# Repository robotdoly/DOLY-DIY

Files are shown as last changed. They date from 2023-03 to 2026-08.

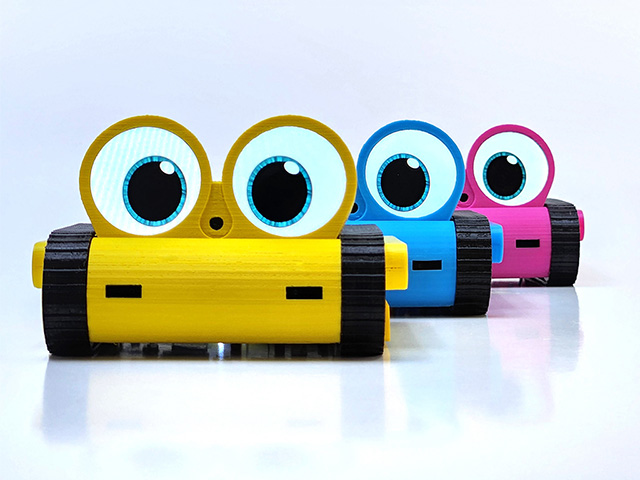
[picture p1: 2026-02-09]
Guide/web/assets/images/printable_doly.jpg

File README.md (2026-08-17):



# DOLY-DIY

Doly robot project repository including **hardware/design files + electronics + software (SDK, libraries, and examples)**.

This repo is meant to be an **all-in-one** place to **learn, remix, and build** the DOLY robot.

---

## What’s included

- **Hardware / Mechanical**
  - CAD / 3D models (STL/STEP/etc.)
  - Assembly references

- **Electronics**
  - Interactive BOMs
  - Schematics / PCB files

- **Software**
  - SDK (C++ & Python)
  - Shared libraries used by the robot
  - Example code (C++ & Python)

- **Documentation**
  - [3D printable Doly assembly guide](https://robotdoly.github.io/DOLY-DIY/maker/)
  - [C++ API documentation](https://robotdoly.github.io/DOLY-DIY/cpp/)
  - [Python API documentation](https://robotdoly.github.io/DOLY-DIY/python/)
  - [AI Integration Developer FAQ](https://github.com/robotdoly/DOLY-DIY/blob/main/SDK/docs/AI_Integration_Developer_FAQ.md)

---

## Repository structure

- `Printables/` — CAD, STLs, STEP
- `Electronics/` — schematics, PCB files, interactive BOMs  
- `SDK/` — SDK, libraries, documents and examples 
- `Guide/`  — 3D printable maker guide,  
- `Images/` — project image files
- `Add-ons/` — add-on files 

---

## Contributing

Contributions are welcome!

Good contributions include:
- bug fixes
- documentation improvements
- new examples
- SDK improvements
- 3D printable add-ons

Please contact us via the [community page](https://community.doly.ai/public/t/contribute); let's integrate your contribution and ensure you receive proper credit.

---

## License

This project is licensed under **CC BY-NC-SA 4.0** (Attribution–NonCommercial–ShareAlike).

See the `LICENSE` file for full terms.  

---

## Links

- Shop: https://shop.doly.ai
- Website: https://doly.ai
- Community: https://community.doly.ai
- Instagram: https://www.instagram.com/robotdoly/
- Facebook: https://www.facebook.com/robotdoly/
- Youtube: https://www.youtube.com/@robotdoly
- GitHub repo: https://github.com/robotdoly/DOLY-DIY

---

## Credits

- Created by **Levent Erenler**
- Commercial use is not permitted. Commercial licenses are available from Limitbit Inc.

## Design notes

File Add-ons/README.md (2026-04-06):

### Visit [doly.ai/add-ons/](https://doly.ai/add-ons/) to view all available add-ons.

For support, questions, or sharing your own designs, please visit the Doly [community](https://community.doly.ai/public/t/add-ons) forum.

Base template design files for custom add-ons can be found in [Add-ons/helpers/base_template](https://github.com/robotdoly/DOLY-DIY/tree/main/Add-ons/helpers/base_template).

Doly servo model files can be found in [Add-ons/helpers/servo](https://github.com/robotdoly/DOLY-DIY/tree/main/Add-ons/helpers/servo).

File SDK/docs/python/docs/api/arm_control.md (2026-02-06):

# ArmControl API reference

Import:

```python
import doly_arm
```

This page documents the public API exposed by the `doly_arm` Python module.

## Enums

### `ArmErrorType`

Values:

- `Abort`
- `Motor`

### `ArmSide`

Values:

- `Both`
- `Left`
- `Right`

### `ArmState`

Values:

- `Running`
- `Completed`
- `Error`

## Classes

### `ArmData`

**Fields**

- **side**
- **angle**

### `ArmEventListener`

Listener interface. Implement this class and register it with `add_listener()` to receive events.

**Methods**

- `onArmComplete(id: int, side: ArmSide) -> None`
  - Called when an arm command completes successfully.
- `onArmError(id: int, side: ArmSide, error_type: ArmErrorType) -> None`
  - Called when an arm command ends with an error.
- `onArmStateChange(side: ArmSide, state: ArmState) -> None`
  - Called when the arm state changes.
- `onArmMovement(side: ArmSide, degree_change: float) -> None`
  - Called to report incremental motion events.

## Functions

### `add_listener(listener: ArmEventListener, priority: bool = False) -> None`

Register a listener object to receive arm events.

**Parameters**

- **listener**: Pointer to a listener instance (must not be null).
- **priority**: If `True`, the listener is inserted with priority ordering (implementation-defined). (default: `False`)

**Notes**

- Callbacks are typically invoked from an internal worker/event thread.

### `remove_listener(listener: ArmEventListener) -> None`

Unregister a listener object.

**Parameters**

- **listener**: Pointer previously passed to AddListener().

### `on_complete(cb: py::function) -> None`

Set a static complete callback (replaces any previous one).
Tip: If you want multiple handlers, use a Python dispatcher function.

**Parameters**

- **cb**:

### `on_error(cb: py::function) -> None`

Set a static error callback (replaces any previous one). Tip: If you want multiple handlers, use a Python dispatcher function.

**Parameters**

- **cb**:

### `on_state_change(cb: py::function) -> None`

Set a static state change callback (replaces any previous one). Tip: If you want multiple handlers, use a Python dispatcher function.

**Parameters**

- **cb**:

### `on_movement(cb: py::function) -> None`

Set a static movement callback (replaces any previous one). Tip: If you want multiple handlers, use a Python dispatcher function.

**Parameters**

- **cb**:

### `clear_listeners() -> None`

Unregister all static callbacks and clear stored Python functions.

### `init() -> int`

Initialize the arm subsystem.

This must be called once before other control functions.

**Returns**

- `int`:

```text
Status code: - 0 : success - 1 : already initialized - -1 : left servo enable pin set failed - -2 : right servo enable pin set failed
```

**Notes**

- After successful init(), isActive() should return true.

### `dispose() -> int`

Dispose/stop the arm subsystem and release resources. Removes the call back functions.

**Returns**

- `int`:

```text
Status code: - 0 : success - 1 : not initialized
```

### `is_active() -> bool`

Check whether the subsystem is active (initialized and running).

**Returns**

- `bool`:

```text
true if active, false otherwise.
```

### `abort(side: ArmSide) -> None`

Abort the current operation for a given side.

This is intended as an emergency/stop action.

**Parameters**

- **side**: Arm side to abort (LEFT/RIGHT/BOTH).

### `get_max_angle() -> int`

Get maximum allowed angle for the arm.

**Returns**

- `int`:

```text
Maximum angle (degrees).
```

### `set_angle(id: int, side: ArmSide, speed: int, angle: int, with_brake: bool = False) -> int`

Command the arm to move to an angle.

The operation is handled asynchronously (non-blocking). Results are reported via: - ArmEventListener::onArmComplete() - ArmEventListener::onArmError() - ArmEventListener::onArmStateChange()

**Parameters**

- **id**: User-defined command identifier (echoed back in completion/error callbacks).
- **side**: Arm side to move (LEFT/RIGHT/BOTH).
- **speed**: Speed percentage in range [1..100].
- **angle**: Target angle in degrees in range [0..getMaxAngle()].
- **with_brake**: If `True`, apply brake/hold behavior at target (implementation-defined). (default: `False`)

**Returns**

- `int`:

```text
Status code: - 0 : success (command accepted) - -1 : not active (init() not called or subsystem not running) - -2 : speed out of range - -3 : angle out of range
```

### `get_state(side: ArmSide) -> ArmState`

Get current operation state for a side.

**Parameters**

- **side**: Arm side.

**Returns**

- `ArmState`:

```text
Current ArmState.
```

### `get_current_angle(side: ArmSide) -> list[ArmData]`

Get the current angle(s) for the requested side(s).

**Parameters**

- **side**: Requested side (LEFT/RIGHT/BOTH).

**Returns**

- `list[ArmData]`:

```text
Vector of ArmData entries. If side == BOTH, the vector may contain 2 elements.
```

### `get_version() -> float`

Get SDK/library version.

Format note from original header: 0.XYZ (3 digits after major).

**Returns**

- `float`:

```text
Version as float.
```

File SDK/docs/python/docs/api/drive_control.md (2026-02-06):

# DriveControl API reference

Import:

```python
import doly_drive
```

This page documents the public API exposed by the `doly_drive` Python module.

## Enums

### `DriveErrorType`

Values:

- `Abort`
- `Force`
- `Rotate`
- `Motor`

### `DriveMotorSide`

Values:

- `Both`
- `Left`
- `Right`

### `DriveState`

Values:

- `Running`
- `Completed`
- `Error`

### `DriveType`

Values:

- `Freestyle`
- `XY`
- `Distance`
- `Rotate`

## Classes

### `DriveEventListener`

Listener interface. Implement this class and register it with `add_listener()` to receive events.

**Methods**

- `on_drive_complete(id: int) -> None`
  - Called when a drive command completes successfully.
- `on_drive_error(id: int, side: DriveMotorSide, type: DriveErrorType) -> None`
  - Called when a drive operation reports an error.
- `on_drive_state_change(drive_type: DriveType, state: DriveState) -> None`
  - Called when the state of a drive operation changes.

## Functions

### `add_listener(listener_obj: DriveEventListener) -> None`

Register a listener object to receive drive events.

**Parameters**

- **listener_obj**: Pointer to a listener instance (must not be null).

**Notes**

- Callbacks are typically invoked from an internal worker/event thread.

### `remove_listener(listener_obj: DriveEventListener) -> None`

Unregister a listener object.

**Parameters**

- **listener_obj**: Pointer previously passed to AddListener().

### `init(imu_off_gx: int = 0, imu_off_gy: int = 0, imu_off_gz: int = 0, imu_off_ax: int = 0, imu_off_ay: int = 0, imu_off_az: int = 0) -> int`

Initialize the drive control module.

IMU offsets are calibration values stored by the platform.

**Parameters**

- **imu_off_gx**: IMU gyro X offset (calibration). (default: `0`)
- **imu_off_gy**: IMU gyro Y offset (calibration). (default: `0`)
- **imu_off_gz**: IMU gyro Z offset (calibration). (default: `0`)
- **imu_off_ax**: IMU accel X offset (calibration). (default: `0`)
- **imu_off_ay**: IMU accel Y offset (calibration). (default: `0`)
- **imu_off_az**: IMU accel Z offset (calibration). (default: `0`)

**Returns**

- `int`:

```text
Status code: - 0 : success - 1 : already active / already initialized - -1 : motor setup failed - -2 : IMU init failed
```

### `dispose(dispose_IMU: bool) -> int`

Dispose/shutdown drive module and release resources. Removes the call back functions.

**Parameters**

- **dispose_IMU**: If `True`, shuts down the IMU module as well.

**Returns**

- `int`:

```text
Status code: - 0 : success - 1 : not active / not initialized
```

### `is_active() -> bool`

Check whether the module is initialized and active.

**Returns**

- `bool`:

```text
true if active, false otherwise.
```

### `abort() -> None`

Abort current drive operation immediately.

Typically used as an emergency stop for autonomous movement. Completion/error events may still be emitted depending on implementation.

### `free_drive(speed: int, is_left: bool, to_forward: bool) -> bool`

Manual motor drive (low-level).

**Parameters**

- **speed**: Motor speed percent (0..100).
- **is_left**: `True` = left motor, `False` = right motor.
- **to_forward**: `True` = forward, `False` = backward.

**Returns**

- `bool`:

```text
true if accepted.
```

**Notes**

- Non-blocking; handled in another thread.

### `go_xy(id: int, x: int, y: int, speed: int, to_forward: bool, with_brake: bool = False, acceleration_interval: int = 0, control_speed: bool = False, control_force: bool = True) -> bool`

Autonomous drive to an (x, y) target (high-level).

**Parameters**

- **id**: User command id (returned in events/callbacks).
- **x**: Target X in your Position coordinate system (units are application-defined).
- **y**: Target Y in your Position coordinate system (same unit as x).
- **speed**: Requested speed percent (0..100).
- **to_forward**: Direction preference for the move.
- **with_brake**: If `True`, brake at the end of motion. (default: `False`)
- **acceleration_interval**: Acceleration step interval (0 = disabled). (default: `0`)
- **control_speed**: Enable speed control dynamically. (default: `False`)
- **control_force**: Enable force/traction control (default `True`). (default: `True`)

**Returns**

- `bool`:

```text
true if command accepted.
```

**Notes**

- Non-blocking; handled in another thread.

### `go_distance(id: int, mm: int, speed: int, to_forward: bool, with_brake: bool = False, acceleration_interval: int = 0, control_speed: bool = False, control_force: bool = True) -> bool`

Autonomous drive for a fixed distance (high-level).

**Parameters**

- **id**: User command id (returned in events/callbacks).
- **mm**: Distance value (named "mm" in API; ensure your implementation uses millimeters).
- **speed**: Requested speed percent (0..100).
- **to_forward**: `True` forward / `False` backward.
- **with_brake**: Brake at the end. (default: `False`)
- **acceleration_interval**: Acceleration step interval (0 = disabled). (default: `0`)
- **control_speed**: Enable speed control dynamically. (default: `False`)
- **control_force**: Enable force/traction control. (default: `True`)

**Returns**

- `bool`:

```text
true if command accepted.
```

**Notes**

- Non-blocking; handled in another thread.

### `go_rotate(id: int, rotate_angle: float, from_center: bool, speed: int, to_forward: bool, with_brake: bool = False, acceleration_interval: int = 0, control_speed: bool = False, control_force: bool = True) -> bool`

Autonomous rotate (high-level).

**Parameters**

- **id**: User command id (returned in events/callbacks).
- **rotate_angle**: Rotation angle in degrees (sign convention is implementation-defined).
- **from_center**: `True` = rotate around center, `False` = rotate around a wheel/edge (implementation-defined).
- **speed**: Requested speed percent (0..100).
- **to_forward**: Direction preference (implementation-defined for rotation).
- **with_brake**: Brake at the end. (default: `False`)
- **acceleration_interval**: Acceleration step interval (0 = disabled). (default: `0`)
- **control_speed**: Enable speed control dynamically. (default: `False`)
- **control_force**: Enable force/traction control. (default: `True`)

**Returns**

- `bool`:

```text
true if command accepted.
```

**Notes**

- Non-blocking; handled in another thread.

### `get_position() -> Position`

Get current estimated position.

**Returns**

- `Position`:

```text
Current Position estimate (see Helper.h for definition/units).
```

### `reset_position() -> None`

Reset current position estimate to (0, 0, 0) (implementation-defined fields).

### `get_state() -> DriveState`

Get current drive state.

**Returns**

- `DriveState`:

```text
Current DriveState.
```

### `get_rpm(is_left: bool) -> float`

Get current motor RPM.

**Parameters**

- **is_left**: `True` = left motor, `False` = right motor.

**Returns**

- `float`:

```text
RPM value (units: revolutions per minute).
```

### `on_complete(cb_obj: void(onComplete)(uint16_t) -> None`

Remove a previously registered “command complete” callback.

**Parameters**

- **cb_obj**: Same function pointer passed to AddListenerOnComplete().

### `on_error(cb_obj: void(onError)(uint16_t id, DriveMotorSide side, DriveErrorType) -> None`

Remove a previously registered error callback.

**Parameters**

- **cb_obj**: Same function pointer passed to AddListenerOnError().

### `on_state_change(cb_obj: void(onChange)(DriveType drive_type, DriveState) -> None`

Remove a previously registered state-change callback.

**Parameters**

- **cb_obj**: Same function pointer passed to AddListenerOnStateChange().

### `clear_listeners() -> None`

Unregister all static callbacks and clear stored Python functions.

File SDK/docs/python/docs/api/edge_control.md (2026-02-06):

# EdgeControl API reference

Import:

```python
import doly_edge
```

This page documents the public API exposed by the `doly_edge` Python module.

## Enums

### `GpioState`

Values:

- `Low`
- `High`

### `GapDirection`

Values:

- `Front`
- `Front_Left`
- `Front_Right`
- `Back`
- `Back_Left`
- `Back_Right`
- `Left`
- `Right`
- `Cross_Left`
- `Cross_Right`
- `All`

### `SensorId`

Values:

- `Back_Left`
- `Back_Right`
- `Front_Left`
- `Front_Right`

## Classes

### `IrSensor`

**Fields**

- **id**
- **state**

### `EdgeEventListener`

Listener interface. Implement this class and register it with `add_listener()` to receive events.

**Methods**

- `onEdgeChange(sensors: list[IrSensor]) -> None`
  - Called when the set of IR sensor states changes.
- `onGapDetect(gap_type: GapDirection) -> None`
  - Called when a gap (e.g. drop-off, missing surface) is detected and categorized.

## Functions

### `add_listener(listener: EdgeEventListener, priority: bool = False) -> None`

Register an EdgeEventListener instance.

**Parameters**

- **listener**: Listener object pointer.
- **priority**: If `True`, the listener may be inserted with higher priority (implementation-defined ordering). (default: `False`)

### `remove_listener(listener: EdgeEventListener) -> None`

Unregister an EdgeEventListener instance.

**Parameters**

- **listener**: Listener object pointer previously registered.

### `clear_listeners() -> None`

Unregister all static callbacks and class-based listeners tracked by the binding.

### `on_change(cb: py::function) -> None`

Set a static on-change callback (replaces any previous one).
Tip: If you want multiple handlers, use a Python dispatcher function.

**Parameters**

- **cb**:

### `on_gap_detect(cb: py::function) -> None`

Set a static gap-detect callback (replaces any previous one).
Tip: If you want multiple handlers, use a Python dispatcher function.

**Parameters**

- **cb**:

### `init() -> int`

Initialize edge sensor control.

Must be called before enabling control or reading sensors.

**Returns**

- `int`:

```text
Status code: - 0 : success - <0 : error (implementation-defined)
```

### `clear_listeners() -> None`

Unregister all static callbacks and clear stored Python functions.

### `dispose() -> int`

Dispose edge sensor control and release resources. Removes the call back functions.

**Returns**

- `int`:

```text
Status code: - 0 : success - 1 : not initialized - -1..-6 : GPIO release failed (specific code indicates which GPIO failed)
```

### `is_active() -> bool`

Check whether edge sensor control is initialized and active.

**Returns**

- `bool`:

```text
true if active, false otherwise.
```

### `enable_control() -> int`

Start the sensor listening thread.

**Returns**

- `int`:

```text
Status code: - 0 : success - 1 : already running - -1 : not initialized
```

**Notes**

- The initialize function enables the module on startup.

### `disable_control() -> int`

Stop the sensor listening thread.

**Returns**

- `int`:

```text
Status code: - 0 : success - 1 : not running - -1 : not initialized
```

### `get_sensors(state: GpioState) -> list[IrSensor]`

Get IR sensors filtered by GPIO state.

**Parameters**

- **state**: Desired GPIO state to filter by. 0 = no ground detected (free) 1 = ground detected

**Returns**

- `list[IrSensor]`:

```text
Vector containing sensors matching the specified state.
```

### `get_version() -> float`

Get current library version.

Original note: format 0.XYZ (3 digits after major).

**Returns**

- `float`:

```text
Version as float.
```

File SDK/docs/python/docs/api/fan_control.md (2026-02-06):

# FanControl API reference

Import:

```python
import doly_fan
```

This page documents the public API exposed by the `doly_fan` Python module.

## Functions

### `init(auto_control: bool) -> int`

Initialize the Fan Control module.

**Parameters**

- **auto_control**: If `True`, automatic temperature control will manage fan speed.

**Returns**

- `int`:

```text
Status code: - 0 : success - 1 : already initialized - <0 : error (implementation-defined)
```

### `dispose() -> int`

Dispose the Fan Control module and release resources.

**Returns**

- `int`:

```text
Status code: - 0 : success - 1 : not initialized - <0 : error
```

### `set_fan_speed(percentage: int) -> int`

Set fan speed as a percentage.

**Parameters**

- **percentage**: Fan speed percentage (0..100).

**Returns**

- `int`:

```text
Status code: - <0 : error
```

**Notes**

- If @c auto_control was enabled in init(), the automatic controller may override
- or adjust the fan speed over time.

### `is_active() -> bool`

Check whether the Fan Control module is active (initialized).

**Returns**

- `bool`:

```text
true if initialized; false otherwise.
```

### `get_version() -> float`

Get current library version.

Original note: format 0.XYZ (3 digits after major).

**Returns**

- `float`:

```text
Version as float.
```

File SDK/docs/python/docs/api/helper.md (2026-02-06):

# Helper API reference

Import:

```python
import doly_helper
```

This page documents the public API exposed by the `doly_helper` Python module.

## Classes

### `Position`

**Fields**

- **head**
- **x**
- **y**

### `Position2F`

**Fields**

- **x**
- **y**

## Functions

### `read_settings() -> int`

Read default settings from the platform settings file.

This is commonly used to load calibration/config values that the SDK uses at runtime.

**Returns**

- `int`:

```text
Status code: - >= 0 : success - -1 : settings file not found - -2 : XML open or parse error
```

### `get_imu_offsets(gx: int, gy: int, gz: int, ax: int, ay: int, az: int) -> int`

Retrieve IMU calibration offsets (gyro/accel).

Reads previously stored IMU offset values. These offsets are typically passed into DriveControl::init(...) to start with calibrated parameters.

**Parameters**

- **gx**: Gyro X offset.
- **gy**: Gyro Y offset.
- **gz**: Gyro Z offset.
- **ax**: Accel X offset.
- **ay**: Accel Y offset.
- **az**: Accel Z offset.

**Returns**

- `int`:

```text
Status code: - 0 : success - -1 : failed to read offsets
```

### `stop_doly_service() -> int`

Stop the background Doly service (if running).

Some applications/tests may need exclusive access to hardware resources owned by the service. This helper provides a unified method to request stopping it.

**Returns**

- `int`:

```text
Status code: - 0 : success - 1 : service not active - -1 : error while stopping service
```

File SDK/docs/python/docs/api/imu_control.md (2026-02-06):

# ImuControl API reference

Import:

```python
import doly_imu
```

This page documents the public API exposed by the `doly_imu` Python module.

## Enums

### `ImuGesture`

Values:

- `Undefined`
- `Move`
- `LongShake`
- `ShortShake`
- `Vibrate`
- `VibrateExtreme`
- `ShockLight`
- `ShockMedium`
- `ShockHard`
- `ShockExtreme`

### `GestureDirection`

Values:

- `Left`
- `Right`
- `Up`
- `Down`
- `Front`
- `Back`

## Classes

### `VectorFloat`

**Fields**

- **x**
- **y**
- **z**

### `YawPitchRoll`

**Fields**

- **yaw**
- **pitch**
- **roll**

### `ImuData`

**Fields**

- **ypr**
- **linear_accel**
- **temperature**

### `ImuEventListener`

Listener interface. Implement this class and register it with `add_listener()` to receive events.

**Methods**

- `onImuUpdate(data: ImuData) -> None`
  - Called when a new IMU sample/update is available.
- `onImuGesture(type: ImuGesture, from: GestureDirection) -> None`
  - Called when a gesture is detected.

## Functions

### `add_listener(listener: ImuEventListener, priority: bool = False) -> None`

Register an ImuEventListener instance.

**Parameters**

- **listener**: Listener object to register.
- **priority**: If `True`, the listener is inserted with higher priority (called earlier). (default: `False`)

### `remove_listener(listener: ImuEventListener) -> None`

Unregister a previously registered ImuEventListener instance.

**Parameters**

- **listener**: Listener object to unregister.

### `on_update(cb: py::function) -> None`

Set a static IMU update callback (replaces any previous one).
Tip: If you want multiple handlers, use a Python dispatcher function.

**Parameters**

- **cb**:

### `on_gesture(cb: py::function) -> None`

Set a static IMU gesture callback (replaces any previous one).
Tip: If you want multiple handlers, use a Python dispatcher function.

**Parameters**

- **cb**:

### `clear_listeners() -> None`

Unregister all static callbacks and clear stored Python functions.

### `init(delay: int = 0, gx: int = 0, gy: int = 0, gz: int = 0, ax: int = 0, ay: int = 0, az: int = 0) -> int`

Initialize the IMU subsystem.

This must be called once before reading IMU data or receiving events.

**Parameters**

- **delay**: Optional delay (milliseconds) before processing events. (default: `0`)
- **gx**: Gyroscope X offset. (default: `0`)
- **gy**: Gyroscope Y offset. (default: `0`)
- **gz**: Gyroscope Z offset. (default: `0`)
- **ax**: Accelerometer X offset. (default: `0`)
- **ay**: Accelerometer Y offset. (default: `0`)
- **az**: Accelerometer Z offset. (default: `0`)

**Returns**

- `int`:

```text
Status code: - 0 : success - 1 : already active - -1 : init failed
```

**Notes**

- Sampling rate 104hz (accel + gyro), 1Hz (temperature)

### `dispose() -> int`

Dispose/stop the IMU subsystem and release resources.

**Returns**

- `int`:

```text
Status code: - 0 : success - 1 : not active - -1 : dispose failed
```

### `calculate_offsets(gx: int, gy: int, gz: int, ax: int, ay: int, az: int) -> int`

Calculate and output sensor offsets.

Typically used to perform a calibration routine and retrieve offsets that can be passed to init() on later boots.

**Parameters**

- **gx**: Output gyroscope X offset.
- **gy**: Output gyroscope Y offset.
- **gz**: Output gyroscope Z offset.
- **ax**: Output accelerometer X offset.
- **ay**: Output accelerometer Y offset.
- **az**: Output accelerometer Z offset.

**Returns**

- `int`:

```text
Status code: - 0 : success - -1 : init failed - -2 : calculation failed
```

### `get_imu_data() -> ImuData`

Get the last IMU reading snapshot.

**Returns**

- `ImuData`:

```text
Latest ImuData captured by the IMU subsystem.
```

**Notes**

- init() must have been called successfully before meaningful data is available.

### `get_temperature() -> float`

Get the last temperature reading from the IMU.

**Returns**

- `float`:

```text
Temperature in degrees Celsius.
```

### `get_version() -> float`

Get current library version.

Original note: format 0.XYZ (3 digits after major).

**Returns**

- `float`:

```text
Version as float.
```

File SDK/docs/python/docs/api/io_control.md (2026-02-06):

# IoControl API reference

Import:

```python
import doly_io
```

This page documents the public API exposed by the `doly_io` Python module.

## Enums

### `GpioState`

Values:

- `Low`
- `High`

## Functions

### `write_pin(id: int, io_pin: int, state: GpioState) -> int`

Write a GPIO state to an IO port pin.

**Parameters**

- **id**: User-defined identifier used for internal tracking/logging (can be any value).
- **io_pin**: IO port pin number (valid range: 0..5).
- **state**: Desired GPIO output state.

**Returns**

- `int`:

```text
Status code: - 0 : success - -1 : invalid GPIO pin (must be IO port pin number 0..5) - -2 : GPIO write error
```

### `read_pin(id: int, io_pin: int) -> GpioState`

Read the current GPIO state of an IO port pin.

**Parameters**

- **id**: User-defined identifier used for internal tracking/logging (can be any value).
- **io_pin**: IO port pin number (valid range: 0..5).

**Returns**

- `GpioState`:

```text
Current GPIO state. If @p io_pin is invalid or a read error occurs, the returned value is implementation-defined (see underlying GPIO layer).
```

### `get_version() -> float`

Get current library version.

Original note: format 0.XYZ (3 digits after major).

**Returns**

- `float`:

```text
Version as float.
```

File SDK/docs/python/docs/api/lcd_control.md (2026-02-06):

# LcdControl API reference

Import:

```python
import doly_lcd
```

This page documents the public API exposed by the `doly_lcd` Python module.

## Enums

### `LcdColorDepth`

Values:

- `L12BIT`
- `L18BIT`

### `LcdSide`

Values:

- `Left`
- `Right`

## Functions

### `init(depth: LcdColorDepth = LcdColorDepth::L12BIT) -> int`

Initialize the LCD device.

**Parameters**

- **depth**: LCD color depth to configure. (default: `LcdColorDepth::L12BIT`)

**Returns**

- `int`:

```text
Status code: - 0 : success - 1 : already initialized - -1 : open device failed - -2 : ioctl failed
```

### `dispose() -> int`

Release resources and deinitialize the LCD device.

**Returns**

- `int`:

```text
Status code: - 0 : success - 1 : already closed or not opened
```

### `is_active() -> bool`

Check whether the LCD subsystem is active (initialized).

**Returns**

- `bool`:

```text
true if initialized; false otherwise.
```

### `lcd_color_fill(side: LcdSide, r: int, g: int, b: int) -> None`

Fill a panel with a solid RGB color.

**Parameters**

- **side**: LCD side to fill.
- **r**: Red component (0..255).
- **g**: Green component (0..255).
- **b**: Blue component (0..255).

### `write_lcd(side: LcdSide, buffer: py::buffer) -> int`

Write buffer into LCD memory.

Size depends on panel resolution and configured color depth. Example: 240x240x3 for 18-bit depth represented as 3 bytes/pixel.

**Parameters**

- **side**:
- **buffer**:

**Returns**

- `int`:

```text
Status code: - 0 : success - -1 : ioctl error - -2 : not active
```

### `get_buffer_size() -> int`

Get required buffer size in bytes for one full frame.

Size depends on panel resolution and configured color depth. Example: 240x240x3 for 18-bit depth represented as 3 bytes/pixel.

**Returns**

- `int`:

```text
Buffer size in bytes.
```

### `get_color_depth() -> LcdColorDepth`

Get the currently configured LCD color depth.

**Returns**

- `LcdColorDepth`:

```text
Current color depth.
```

### `set_brightness(value: int) -> None`

Set LCD backlight brightness.

**Parameters**

- **value**: Brightness value (min = 0, max = 10).

### `to_lcd_buffer(input: py::buffer, input_rgba: bool = False) -> bytes`

Convert buffer to LCD buffer based on LCD depth.

**Parameters**

- **input**:
- **input_rgba**:  (default: `False`)

**Returns**

- `bytes`:

```text
Buffer array.
```

### `get_version() -> float`

Get current library version.

Original note: format 0.XYZ (3 digits after major).

**Returns**

- `float`:

```text
Version as float.
```

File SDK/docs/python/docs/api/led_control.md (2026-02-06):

# LedControl API reference

Import:

```python
import doly_led
```

This page documents the public API exposed by the `doly_led` Python module.

## Enums

### `LedSide`

Values:

- `Both`
- `Left`
- `Right`

### `LedActivityState`

Values:

- `Free`
- `Running`
- `Completed`

### `LedErrorType`

Values:

- `Abort`

## Classes

### `LedActivity`

**Fields**

- **mainColor**
- **fadeColor**
- **fade_time**
- **state**

### `LedEventListener`

Listener interface. Implement this class and register it with `add_listener()` to receive events.

**Methods**

- `onLedComplete(id: int, side: LedSide) -> None`
  - Called when an activity completes.
- `onLedError(id: int, side: LedSide, type: LedErrorType) -> None`
  - Called when an activity fails or is aborted.

## Functions

### `add_listener(listener: LedEventListener, priority: bool = False) -> None`

Register a LedEventListener instance.

**Parameters**

- **listener**: Listener object to register.
- **priority**: If `True`, the listener is inserted with higher priority (called earlier). (default: `False`)

### `remove_listener(listener: LedEventListener) -> None`

Unregister a previously registered LedEventListener instance.

**Parameters**

- **listener**: Listener object to unregister.

### `on_complete(cb: py::function) -> None`

Set a static complete callback (replaces any previous one).
Tip: If you want multiple handlers, use a Python dispatcher function.

**Parameters**

- **cb**:

### `on_error(cb: py::function) -> None`

Set a static error callback (replaces any previous one).
Tip: If you want multiple handlers, use a Python dispatcher function.

**Parameters**

- **cb**:

### `clear_listeners() -> None`

Unregister all static callbacks and clear stored Python functions.

### `init() -> int`

Initialize the LED subsystem.

**Returns**

- `int`:

```text
Status code: - 0 : success - 1 : already initialized - -1 : R Left GPIO init failed - -2 : G Left GPIO init failed - -3 : B Left GPIO init failed - -4 : R Right GPIO init failed - -5 : G Right GPIO init failed - -6 : B Right GPIO init failed
```

### `dispose() -> int`

Stop the worker thread and release resources.

**Returns**

- `int`:

```text
Status code: - 0 : success - -1..-6 : GPIO pin release failed.
```

### `is_active() -> bool`

Check whether the LED subsystem is active (initialized).

**Returns**

- `bool`:

```text
true if initialized; false otherwise.
```

### `abort(side: LedSide) -> None`

Abort any running activity on the given side.

**Parameters**

- **side**: LED side to abort.

### `process_activity(id: int, side: LedSide, activity: LedActivity) -> None`

Set a LED activity to be processed asynchronously.

This is a non-blocking operation. The internal worker processes the activity and completion/error is reported via LedEvent callbacks.

**Parameters**

- **id**: User-defined activity identifier (forwarded to completion/error events).
- **side**: LED side to run the activity on.
- **activity**: Activity parameters (colors, fade time).

### `get_version() -> float`

Get current library version.

Original note: format 0.XYZ (3 digits after major).

**Returns**

- `float`:

```text
Version as float.
```

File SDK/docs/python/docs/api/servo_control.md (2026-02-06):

# ServoControl API reference

Import:

```python
import doly_servo
```

This page documents the public API exposed by the `doly_servo` Python module.

## Enums

### `ServoId`

Values:

- `Servo0`
- `Servo1`

## Classes

### `ServoEventListener`

Listener interface. Implement this class and register it with `add_listener()` to receive events.

**Methods**

- `onServoAbort(id: int, channel: ServoId) -> None`
  - Called when a servo action is aborted.
- `onServoError(id: int, channel: ServoId) -> None`
  - Called when a servo action fails.
- `onServoComplete(id: int, channel: ServoId) -> None`
  - Called when a servo action completes successfully.

## Functions

### `add_listener(listener: ServoEventListener, priority: bool = False) -> None`

Register a class-based listener (kept alive by the binding until removed/cleared).

**Parameters**

- **listener**:
- **priority**:  (default: `False`)

### `remove_listener(listener: ServoEventListener) -> None`

Unregister a class-based listener.

**Parameters**

- **listener**:

### `on_complete(cb: py::function) -> None`

Set a static servo complete callback (replaces any previous one).
Tip: If you want multiple handlers, use a Python dispatcher function.

**Parameters**

- **cb**:

### `on_abort(cb: py::function) -> None`

Set a static servo abort callback (replaces any previous one).
Tip: If you want multiple handlers, use a Python dispatcher function.

**Parameters**

- **cb**:

### `on_error(cb: py::function) -> None`

Set a static servo error callback (replaces any previous one).
Tip: If you want multiple handlers, use a Python dispatcher function.

**Parameters**

- **cb**:

### `clear_listeners() -> None`

Unregister all static callbacks and clear stored Python functions.

### `init() -> int`

Initialize the servo subsystem.

**Returns**

- `int`:

```text
Status code: - 0 : success - -1 : SERVO_0 setup failed - -2 : SERVO_1 setup failed
```

### `set_servo(id: int, channel: ServoId, angle: float, speed: int = 100, invert: bool = False) -> int`

Set a servo target angle.

**Parameters**

- **id**: User-defined action identifier (forwarded to event callbacks).
- **channel**: Servo channel to control.
- **angle**: Target angle (degrees).
- **speed**: Speed percentage (valid range: 0..100). (default: `100`)
- **invert**: If `True`, invert the direction/orientation for the given channel. (default: `False`)

**Returns**

- `int`:

```text
Status code: - 0 : success - -1 : max angle exceed error - -2 : speed range error (0..100) - -3 : undefined channel - -4 : not initialized
```

### `abort(channel: ServoId) -> int`

Abort an ongoing servo action.

**Parameters**

- **channel**: Servo channel to abort.

**Returns**

- `int`:

```text
Status code: - 0 : success - -1 : failed
```

### `release(channel: ServoId) -> int`

Release servo hold (disable holding torque) for a channel.

**Parameters**

- **channel**: Servo channel to release.

**Returns**

- `int`:

```text
Status code: - 0 : success - -1 : failed - -2 : busy/running
```

### `dispose() -> int`

Dispose/stop the servo subsystem and release resources.

**Returns**

- `int`:

```text
Status code (implementation-defined).
```

### `get_version() -> float`

Get current library version.

Original note: format 0.XYZ (3 digits after major).

**Returns**

- `float`:

```text
Version as float.
```

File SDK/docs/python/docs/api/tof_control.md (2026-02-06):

# TofControl API reference

Import:

```python
import doly_tof
```

This page documents the public API exposed by the `doly_tof` Python module.

## Enums

### `TofError`

Values:

- `NoError`
- `VcselContinuityTest`
- `VcselWatchdogTest`
- `VcselWatchdog`
- `Pll1Lock`
- `Pll2Lock`
- `EarlyConvergenceEstimate`
- `MaxConvergence`
- `NoTargetIgnore`
- `MaxSignalToNoiseRatio`
- `RawRangingAlgoUnderflow`
- `RawRangingAlgoOverflow`
- `RangingAlgoUnderflow`
- `RangingAlgoOverflow`
- `FilteredByPostProcessing`
- `DataNotReady`

### `TofSide`

Values:

- `Left`
- `Right`

### `TofGestureType`

Values:

- `Undefined`
- `ObjectComing`
- `ObjectGoing`
- `Scrubing`
- `ToLeft`
- `ToRight`

## Classes

### `TofGesture`

**Fields**

- **type**
- **range_mm**

### `TofData`

**Fields**

- **update_ms**
- **range_mm**
- **error**
- **side**

### `TofEventListener`

Listener interface. Implement this class and register it with `add_listener()` to receive events.

**Methods**

- `onProximityGesture(left: TofGesture, right: TofGesture) -> None`
  - Called when a proximity gesture is detected.
- `onProximityThreshold(left: TofData, right: TofData) -> None`
  - Called when proximity threshold is reached (if enabled).

## Functions

### `add_listener(listener: TofEventListener, priority: bool = False) -> None`

Register a TofEventListener instance.

**Parameters**

- **listener**: Listener object to register.
- **priority**: If `True`, the listener is inserted with higher priority (called earlier). (default: `False`)

### `remove_listener(listener: TofEventListener) -> None`

Unregister a previously registered TofEventListener instance.

**Parameters**

- **listener**: Listener object to unregister.

### `on_proximity_gesture(cb: py::function) -> None`

Set a static proximity-gesture callback (replaces any previous one).
Tip: If you want multiple handlers, use a Python dispatcher function.

**Parameters**

- **cb**:

### `on_proximity_threshold(cb: py::function) -> None`

Set a static proximity-threshold callback (replaces any previous one).
Tip: If you want multiple handlers, use a Python dispatcher function.

**Parameters**

- **cb**:

### `clear_listeners() -> None`

Unregister all static callbacks and clear stored Python functions.

### `init(offset_left: int = 0, offset_right: int = 0) -> int`

Initialize ToF sensors.

**Parameters**

- **offset_left**: Offset to apply to left sensor readings. (default: `0`)
- **offset_right**: Offset to apply to right sensor readings. (default: `0`)

**Returns**

- `int`:

```text
Status code: - 0 : success - 1 : already running - -1 : both sensor init failed - -2 : left sensor init failed - -3 : right sensor init failed
```

### `dispose() -> int`

Dispose/stop the ToF subsystem and release resources.

**Returns**

- `int`:

```text
Status code: - 0 : success - 1 : not initialized
```

### `setup_continuous(interval_ms: int = 50, distance: int = 0) -> int`

Configure continuous reading for gesture detection and threshold events.

**Parameters**

- **interval_ms**: Read interval in milliseconds (max = 2550 ms). Use 0 to stop continuous reading. (default: `50`)
- **distance**: Proximity threshold distance in millimeters: - 0 disables proximity threshold events - 120 mm is the maximum supported threshold (default: `0`)

**Returns**

- `int`:

```text
Status code: - 0 : success - 1 : already running - -1 : interval_ms out of range (max = 2550) - -2 : ToF devices not ready - -3 : proximity distance out of range (0..120 mm)
```

**Notes**

- For better gesture detection, recommended interval is 30..80 ms (ideal: 50 ms).

### `get_sensors_data() -> list[TofData]`

Read both sensors once and return the latest values.

Continuous setup is not required for single reads.

**Returns**

- `list[TofData]`:

```text
Vector containing left and right sensor data.
```

### `is_active() -> bool`

Check whether the ToF subsystem is active (initialized).

**Returns**

- `bool`:

```text
true if initialized; false otherwise.
```

### `is_reading() -> bool`

Check whether the subsystem is currently performing frequent/continuous readings.

**Returns**

- `bool`:

```text
true if continuous reading is active; false otherwise.
```

### `get_version() -> float`

Get current library version.

Original note: format 0.XYZ (3 digits after major).

**Returns**

- `float`:

```text
Version as float.
```

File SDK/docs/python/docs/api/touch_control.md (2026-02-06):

# TouchControl API reference

Import:

```python
import doly_touch
```

This page documents the public API exposed by the `doly_touch` Python module.

## Enums

### `TouchSide`

Values:

- `Both`
- `Left`
- `Right`

### `TouchState`

Values:

- `Up`
- `Down`

### `TouchActivity`

Values:

- `Patting`
- `Disturb`

## Classes

### `TouchEventListener`

Listener interface. Implement this class and register it with `add_listener()` to receive events.

**Methods**

- `onTouchEvent(side: TouchSide, state: TouchState) -> None`
  - Called on touch state changes.
- `onTouchActivityEvent(side: TouchSide, activity: TouchActivity) -> None`
  - Called on detected touch activity (high-level pattern).

## Functions

### `add_listener(listener: TouchEventListener, priority: bool = False) -> None`

Register a TouchEventListener instance.

**Parameters**

- **listener**: Listener object to register.
- **priority**: If `True`, the listener is inserted with higher priority (called earlier). (default: `False`)

### `remove_listener(listener: TouchEventListener) -> None`

Unregister a previously registered TouchEventListener instance.

**Parameters**

- **listener**: Listener object to unregister.

### `on_touch(cb: py::function) -> None`

Set a static touch callback (replaces any previous one).
Tip: If you want multiple handlers, use a Python dispatcher function.

**Parameters**

- **cb**:

### `on_touch_activity(cb: py::function) -> None`

Set a static touch-activity callback (replaces any previous one).
Tip: If you want multiple handlers, use a Python dispatcher function.

**Parameters**

- **cb**:

### `clear_listeners() -> None`

Unregister all static callbacks and clear stored Python functions.

### `init() -> int`

Initialize the touch controller and start the worker thread.

**Returns**

- `int`:

```text
Status code: - 0 : success - 1 : already initialized (no-op) - -1 : left sensor GPIO initialization failed - -2 : right sensor GPIO initialization failed
```

### `dispose() -> int`

Stop the worker thread and release resources.

**Returns**

- `int`:

```text
Status code: - 0 : success - -1 : left sensor GPIO release failed - -2 : right sensor GPIO release failed
```

### `is_active() -> bool`

Check whether the touch controller is active (initialized and running).

**Returns**

- `bool`:

```text
true if active; false otherwise.
```

### `is_touched(side: TouchSide) -> bool`

Check whether the given side is currently touched.

**Parameters**

- **side**: Sensor side to query.

**Returns**

- `bool`:

```text
true if touched; false otherwise.
```

### `get_version() -> float`

Get current library version.

Original note: format 0.XYZ (3 digits after major).

**Returns**

- `float`:

```text
Version as float.
```

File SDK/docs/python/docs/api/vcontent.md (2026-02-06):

# VContent API reference

Import:

```python
import doly_vcontent
```

This page documents the public API exposed by the `doly_vcontent` Python module.

## Classes

### `VContent`

**Fields**

- **active_frame_id**: Selected frame on load.
- **ft**: Total frames in sequence.
- **width**: Frame width.
- **height**: Frame height.
- **path**: Source path.
- **alpha**: True if content has alpha channel.
- **color12Bit**: True if content is 12-bit color (or more).
- **ratio**: Frame ratio divider.
- **loop**: Loop count (0 = forever).
- **frames**: Raw frames as list of byte arrays (debug/advanced).

**Methods**

- `__init__() -> None`
  - Create an empty VContent.
- `is_ready() -> bool`
  - Return True if the content has been loaded successfully.
- `get_frame_bytes(index: int = 0) -> bytes`
  - Get a frame as bytes (raw RGB/RGBA buffer as stored by the library).
- `get_image(path: str, isRGBA: bool, set12Bit: bool) -> VContent`
  - Load a PNG from path and return a VContent.
    isRGBA: True if loaded image has alpha.
    set12Bit: convert to 12-bit color depth.

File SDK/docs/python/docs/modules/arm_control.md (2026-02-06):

# ArmControl (Python)

## Import

```python
import doly_arm
```

## Minimal working example

Below is the module’s `example.py` as a starting point.

```python
"""
example.py

This example shows how to implement an event listener in Python
(similar to `class MyListener : public ArmEventListener` in C++) and use it
with the ArmControl API.

It demonstrates:
- Initializing the arm controller
- Creating a listener class by inheriting from ArmEventListener
- Registering the listener instance (non-static / object-based)
- Sending a movement command using set_angle()
- Reading back the current angle(s)
- Cleaning up (remove_listener + dispose)

Important notes about python wrapper:
- You MUST keep a Python reference to the listener object while it is registered.
  If the listener is garbage-collected, the C++ side may still hold a pointer to it,
  which can cause a crash.
"""

import time
import doly_arm as arm
import doly_helper as helper

class MyListener(arm.ArmEventListener):
    def onArmComplete(self, id, side):
        print("[info] complete", id, side)

    def onArmError(self, id, side, errorType):
        print("[error] error", id, side, errorType)

    def onArmStateChange(self, side, state):
        print("[info] state", side, state)

    def onArmMovement(self, side, degreeChange):
        print("[info] move", side, degreeChange)

def main():

    # Version
    try:
        print(f"[info] ArmControl Version: {arm.get_version():.3f}")
    except AttributeError:
        pass

    # *** IMPORTANT *** 
    # Stop doly service if running,
    # otherwise instance of libraries cause conflict	
    if helper.stop_doly_service() < 0: 
        print("[error] Doly service stop failed")
        return -1
    
    # *** IMPORTANT *** 
    # Read settings for servo calibration data, otherwise arm control won't work.
    # one time read is sufficient for the lifetime of the application	
    if helper.read_settings() < 0: 
        print("[error] Read settings failed")
        return -2

    # Initialize ArmControl
    rc = arm.init()
    if rc < 0:
        print(f"[error] ArmControl.init failed rc={rc}")
        return -2  

    # add event listener
    listener = MyListener()
    arm.add_listener(listener, priority=False)

    # Example command
    cmd_id = 1
    rc = arm.set_angle(cmd_id, arm.ArmSide.Both, speed=30, angle=90, with_brake=False)
    if rc < 0:
        print(f"[error] set_angle failed rc={rc}")
        return -3

    # Wait until done (simple polling example)
    while arm.get_state(arm.ArmSide.Both) != arm.ArmState.Completed:
        time.sleep(0.05)

    angles = arm.get_current_angle(arm.ArmSide.Both)
    for a in angles:
        print(f"angle: side={a.side} angle={a.angle}")    

    # Cleanup     
    arm.dispose()       
    time.sleep(0.2)

    return 0

if __name__ == "__main__":
    raise SystemExit(main())
```

## Common tasks

- **Stop Doly service**
- **Initialize**
- **Add event listener**
- **Set angle**
- **Read state / values**
- **Dispose / cleanup**

## Notes

- **Platform:** Raspberry Pi OS
- **Python:** 3.11
- **Installed on robot:** Yes (preinstalled)

## API reference

See: [API reference](../api/arm_control.md)

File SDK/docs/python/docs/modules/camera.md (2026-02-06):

# Camera (Python)

## Import

```python
import doly_camera
```

## Minimal working example

Below is the module’s `example.py` as a starting point.

```python
import cv2
import doly_camera

def main():
    print("Initializing camera")

    cam = doly_camera.PiCamera()

    cam.options.photo_width = 3280
    cam.options.photo_height = 2464
    cam.options.video_width = 1280
    cam.options.video_height = 960
    cam.options.framerate = 15
    cam.options.verbose = False

    # -----------------------------
    # Single frame capture example
    # -----------------------------
    if cam.start_photo():
        frame = cam.capture_photo()  # numpy array or None
        if frame is None:
            print("[error] Camera read buffer failed at capture!")
            return -3

        cv2.imwrite("capture.jpg", frame)
        print("Frame saved!")
        cam.stop_photo()

    # -----------------------------
    # Video frame capture example
    #
    # This example uses an OpenCV imshow() window to display captured frames. (X11 forwarding over SSH)
    # However, you have several options to view the camera output.
    # Here are a few examples:
    # 1) Stream frames over the network (probably fast and best option, requires addditional coding)
    #		inside your capture loop:
    #		std::vector<uchar> jpeg;
    #		cv::imencode(".jpg", frame, jpeg); (optional: reduce JPEG quality for small data)
    #		-> send jpeg over socket / HTTP
    # 2) X11 forwarding over SSH (simple, but slow)
    #
    #
    # This example uses an OpenCV imshow() window to display captured frames (X11 forwarding over SSH).
    #
    # Note:
    # - The image window may NOT be displayed when running with root privileges
    #   (this can cause GTK/X11 permission errors).
    # - X11 forwarding is required to display the window over SSH.
    # - Make sure your SSH client supports X11 forwarding.
    #
    # To test whether X11 forwarding is working correctly:
    #   sudo apt install -y x11-apps
    #   xclock
    # If X11 is working, a clock window should appear.
    #
    # Also verify that DISPLAY is set:
    #   echo $DISPLAY
    # It should show something like "localhost:11.0"
    # -----------------------------
    if cam.start_video():
        print("Video window is live! Press ESC to quit!")

        cv2.namedWindow("Camera", cv2.WINDOW_NORMAL)
        cv2.resizeWindow("Camera", 640, 480)

        time_out_ms = 1500
        total_frame = 300 #test frame count

        while total_frame > 0:
            total_frame -= 1

            frame = cam.get_video_frame(time_out_ms)  # numpy array or None
            if frame is not None: 
                # resize frame for fast X11 transfer
                resized = cv2.resize(frame, (640, 480), interpolation=cv2.INTER_AREA)         
                cv2.imshow("Camera", resized)
                k = cv2.waitKey(1) & 0xFF
                if k == 27:  # ESC
                    break
            else:
                print("[warn] getVideoFrame() timeout/fail")

        cam.stop_video()

    cv2.destroyAllWindows()
    return 0

if __name__ == "__main__":
    raise SystemExit(main())
```

## Common tasks

- **Initialize**
- **Capture frame(s)**
- **Process frame**
- **Dispose / cleanup**

## Notes

- **Platform:** Raspberry Pi OS
- **Python:** 3.11
- **Installed on robot:** Yes (preinstalled)

## API reference

See: [API reference](../api/camera.md)

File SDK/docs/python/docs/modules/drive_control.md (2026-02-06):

# DriveControl (Python)

## Import

```python
import doly_drive
```

## Minimal working example

Below is the module’s `example.py` as a starting point.

```python
"""
example.py

It demonstrates:
- Initializing the drive controller
- Registering the static event listener
- Sending drive commands using multiple options
- Reading the current estimated position
- Cleaning up

"""

import time
import doly_drive as drive
import doly_helper as helper

def on_drive_complete(cmd_id: int):
    print(f"[info] Drive complete id={cmd_id}")

def on_drive_error(cmd_id: int, side, err_type):
    # side is DriveErrorSide enum, err_type is DriveErrorType enum
    print(f"[error] Drive error id={cmd_id} side={int(side)} type={int(err_type)}")

def on_drive_state_change(drive_type, state):
    print(f"[info] Drive state type={int(drive_type)} state={int(state)}")

def main():
    # Version
    try:
        print(f"[info] DriveControl Version: {drive.get_version():.3f}")
    except AttributeError:
        pass

    # *** IMPORTANT *** 
    # Stop doly service if running,
    # otherwise instance of libraries cause conflict	
    if helper.stop_doly_service() < 0: 
        print("[error] Doly service stop failed")
        return -1

    # Register static event listeners 
    drive.on_complete(on_drive_complete)
    drive.on_error(on_drive_error)
    drive.on_state_change(on_drive_state_change)

    # Initialize DriveControl with zero IMU offsets (example)
    # For better performance provide actual calibrated IMU offsets.
    # Check examples_helper.py for more information
    rc = drive.init()
    if rc != 0:
        print("[error] DriveControl init failed")
        return -2

    speed = 50  # example speed % (0..100)

    # Example 1: go 100mm forward, brake at end
    drive.go_distance(1, 100, speed, True, True)

    # Example 2: Rotate 45 degrees counterclockwise on wheel, with brake at end
    # drive.go_rotate(2, -45.0, False, speed, True, True)

    # Example 3: Go to X= -100mm, Y= 200mm, approaching forward with acceleration, without brake at end
    # drive.go_xy(1, -100.0, 200.0, speed, True, False, 50)

    # Example 4: Free drive left and right wheels forward at specified speed for 2 seconds
    # drive.free_drive(speed, False, True)  # Low-level drive right
    # drive.free_drive(speed, True, True)   # Low-level drive left
    # time.sleep(2.0)
    # Stop driving wheels
    # drive.free_drive(0, False, True)
    # drive.free_drive(0, True, True)

    # Wait until done (simple polling example)
    while drive.get_state() == drive.DriveState.Running:
        time.sleep(0.05)

    # Get final position
    pos = drive.get_position()
    print(f"[info] Robot pos x={pos.x} y={pos.y} head={pos.head}")

    # Cleanup
    drive.dispose(True)  # dispose IMU as well   

    return 0

if __name__ == "__main__":
    raise SystemExit(main())
```

## Common tasks

- **Stop Doly service**
- **Initialize**
- **Add event listener**
- **Set drive command**
- **Read state / values**
- **Dispose / cleanup**

## Notes

- **Platform:** Raspberry Pi OS
- **Python:** 3.11
- **Installed on robot:** Yes (preinstalled)

This module uses `/dev/doly_*` devices. Permissions are configured by default; however, if you encounter issues, ensure user permissions are correctly set (see **Troubleshooting → Permissions**).

## API reference

See: [API reference](../api/drive_control.md)

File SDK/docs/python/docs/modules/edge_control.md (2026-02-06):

# EdgeControl (Python)

## Import

```python
import doly_helper
```

## Minimal working example

Below is the module’s `example.py` as a starting point.

```python
"""
example.py

It demonstrates:
- Initializing the edge controller
- Registering the static event listener
- Cleaning up (remove_listener + dispose)

"""

import time
import doly_helper as helper
import doly_edge as edge

def on_edge_change(sensors):
    print("[info] Edge change:", [(s.id, s.state) for s in sensors])

def main():

    # Version
    try:
        print(f"[info] EdgeControl Version: {edge.get_version():.3f}")
    except AttributeError:
        pass

    # *** IMPORTANT *** 
    # Stop doly service if running,
    # otherwise instance of libraries cause conflict	
    if helper.stop_doly_service() < 0: 
        print("[error] Doly service stop failed")
        return -1

    # Initialize ArmControl
    rc = edge.init()
    if rc < 0:
        print(f"[error] EdgeControl.init failed rc={rc}")
        return -2  

    # Register static event listeners 
    edge.on_change(on_edge_change)    

    # Run for 20 seconds to test edge detection
    print(f"[info] Run for 20 seconds to test edge detection")
    time.sleep(20) 

    # Cleanup     
    edge.dispose()       
    time.sleep(0.2) 

    return 0

if __name__ == "__main__":
    raise SystemExit(main())
```

## Common tasks

- **Stop Doly service**
- **Initialize**
- **Add event listener**
- **Read state / values**
- **Dispose / cleanup**

## Notes

- **Platform:** Raspberry Pi OS
- **Python:** 3.11
- **Installed on robot:** Yes (preinstalled)

## API reference

See: [API reference](../api/edge_control.md)

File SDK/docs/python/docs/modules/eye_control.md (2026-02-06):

# EyeControl (Python)

## Import

```python
import doly_helper
```

## Minimal working example

Below is the module’s `example.py` as a starting point.

```python
"""
example.py

It demonstrates:
- Initializing the eye controller
- Registering the static event listeners
- Changing Iris and color
- Animating eyes with predefined animations
- Using a custom image for eye parts
- Setting/getting position of iris 
- Cleaning up (remove_listener + dispose)

"""

import time
import doly_helper as helper
import doly_eye as eye
from doly_color import ColorCode
from doly_vcontent import VContent

def on_eye_start(anim_id: int):
    print(f"[info] Eye animation start id:{anim_id}")

def on_eye_complete(anim_id: int):
    print(f"[info] Eye animation complete id:{anim_id}")

def on_eye_abort(anim_id: int):
    print(f"[warn] Eye animation abort id:{anim_id}")

def main():

    # Version
    try:
        print(f"[info] EyeControl Version:{eye.get_version():.3f}")
    except AttributeError:
        pass

    # *** IMPORTANT ***
    # Stop doly service if running,
    # otherwise instance of libraries cause conflict
    if helper.stop_doly_service() < 0:
        print("[error] Doly service stop failed")
        return -1

    # Initialize EyeControl
    rc = eye.init(ColorCode.Blue, ColorCode.White)
    if rc != 0:
        print("[error] EyeControl init failed")
        return -2

    # Register static event listeners
    eye.on_start(on_eye_start)
    eye.on_complete(on_eye_complete)
    eye.on_abort(on_eye_abort)

    time.sleep(3)

    # Example: Change iris
    eye.set_iris(eye.IrisShape.Modern, ColorCode.DarkGreen, eye.EyeSide.Both)

    time.sleep(3)

    # Example: Set Animation (non-blocking)
    eye.set_animation(1, eye.expressions.EXCITED)

    # Wait until animation complete (same as while (EyeControl::isAnimating()))
    while eye.is_animating():
        time.sleep(0.01)

    time.sleep(3)

    # Example: Using custom images for lids, iris or background
    visual = VContent.get_image("/.doly/images/lids/11B.png", True, True)

    if not visual.is_ready():
        print("[error] image load failed!")
    else:
        # EyeControl::setLid(&visual, false, EyeSide::BOTH);  (bottom lid)
        ret = eye.set_lid_image(visual, False, eye.EyeSide.Both)
        if ret < 0:
            print(f"[error] Set eye lid failed err:{ret}")

    # EyeControl::setPosition(EyeSide::BOTH, 120, 120, 1.2, 1.2, 0, 180);
    eye.set_position(eye.EyeSide.Both, 120, 120, 1.2, 1.2, 0, 180)

    # EyeControl::getIrisPosition(EyeSide::LEFT, x, y);
    rc, x, y = eye.get_iris_position(eye.EyeSide.Left)
    print(f"[info] Left iris position: {x},{y} (rc={rc})")

    # Cleanup callbacks (optional)
    eye.dispose()

    return 0

if __name__ == "__main__":
    raise SystemExit(main())
```

## Common tasks

- **Stop Doly service**
- **Initialize**
- **Add event listeners for animations**
- **Customize eyes**
- **Set animation**
- **Dispose / cleanup**

## Notes

- **Platform:** Raspberry Pi OS
- **Python:** 3.11
- **Installed on robot:** Yes (preinstalled)

This module uses `/dev/doly_*` devices. Permissions are configured by default; however, if you encounter issues, ensure user permissions are correctly set (see **Troubleshooting → Permissions**).

## API reference

See: [API reference](../api/eye_control.md)

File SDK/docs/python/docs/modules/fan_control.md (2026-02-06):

# FanControl (Python)

## Import

```python
import doly_helper
```

## Minimal working example

Below is the module’s `example.py` as a starting point.

```python
"""
example.py

It demonstrates:
- Initializing the Fan controller (manual mode)
- Seting Fan speed
- Cleaning up (dispose)

"""

import time
import doly_helper as helper
import doly_fan as fan

def main():

    # Version
    try:
        print(f"[info] FanControl Version: {fan.get_version():.3f}")
    except AttributeError:
        pass

    # *** IMPORTANT *** 
    # Stop doly service if running,
    # otherwise instance of libraries cause conflict	
    if helper.stop_doly_service() < 0: 
        print("[error] Doly service stop failed")
        return -1
    
    # Initialize Fan Control
    # auto_control = False: we will control fan speed manually in this example
    # auto_control = True: automatic fan control will try to manage CPU temperature under 70 degree Celsius
    rc = fan.init(False)
    if rc < 0:
        print(f"[error] FanControl.init failed rc={rc}")
        return -2
    
    # Set fan speed to 100%
    fan.set_fan_speed(100)
    print("[info] Fan speed set to 100%")
    
    # wait for X seconds to test it
    time.sleep(7)

    #Turn off fan
    fan.set_fan_speed(0)
    print("[info] Fan turned off")

    # Cleanup
    fan.dispose()  
    time.sleep(0.2) 

    return 0

if __name__ == "__main__":
    raise SystemExit(main())
```

## Common tasks

- **Stop Doly service**
- **Initialize**
- **Set fan speed**
- **Dispose / cleanup**

## Notes

- **Platform:** Raspberry Pi OS
- **Python:** 3.11
- **Installed on robot:** Yes (preinstalled)

This module uses `/dev/doly_*` devices. Permissions are configured by default; however, if you encounter issues, ensure user permissions are correctly set (see **Troubleshooting → Permissions**).

## API reference

See: [API reference](../api/fan_control.md)

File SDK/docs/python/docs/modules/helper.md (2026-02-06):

# Helper (Python)

## Import

```python
import doly_helper
```

## Minimal working example

Below is the module’s `example.py` as a starting point.

```python
import doly_helper as helper

def main():
    # Read settings
    res = helper.read_settings()
    if res < 0:
        print(f"[info] Read settings failed with code: {res}")
        return 1

    # Get IMU offsets
    res, gx, gy, gz, ax, ay, az = helper.get_imu_offsets()
    if res < 0:
        print(f"[info] Get IMU offsets failed with code: {res}")
        return 1

    print(f"[info] IMU Offsets - Gx:{gx} Gy:{gy} Gz:{gz} Ax:{ax} Ay:{ay} Az:{az}")
    return 0

if __name__ == "__main__":
    raise SystemExit(main())
```

## Common tasks

- **Stop Doly service**
- **Read settings**

## Notes

- **Platform:** Raspberry Pi OS
- **Python:** 3.11
- **Installed on robot:** Yes (preinstalled)

## API reference

See: [API reference](../api/helper.md)

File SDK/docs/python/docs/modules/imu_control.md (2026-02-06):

# ImuControl (Python)

## Import

```python
import doly_helper
```

## Minimal working example

Below is the module’s `example.py` as a starting point.

```python
"""
example.py

It demonstrates:
- Initializing the IMU controller
- Registering the static event listeners
- Wait for a while to test sensor events
- Cleaning up (dispose)

"""

import time
import doly_helper as helper
import doly_imu as imu

def on_imu_update(data):
    print(f"[info] yaw:{data.ypr.yaw} pitch:{data.ypr.pitch} roll:{data.ypr.roll}")

def on_imu_gesture(gesture, direction):
    print(f"[warn] gesture:{gesture} direction:{direction}")

def main():

    # Version
    try:
        print(f"[info] ImuControl Version: {imu.get_version():.3f}")
    except AttributeError:
        pass

    # *** IMPORTANT *** 
    # Stop doly service if running,
    # otherwise instance of libraries cause conflict	
    if helper.stop_doly_service() < 0: 
        print("[error] Doly service stop failed")
        return -1
    
    # For better performance provide actual calibrated IMU offsets or calculate them once after initialization
	# and use them for next initializations.
	# in this example we will use Helper to get previously saved offsets 

	# Read settings
	# one time read is sufficient for the lifetime of the application
    if helper.read_settings() < 0: 
        print("[error] Doly service stop failed")
        return -1
    
    # Get pre defined IMU offsets    
    rc, gx, gy, gz, ax, ay, az = helper.get_imu_offsets()
    if rc < 0:
        print(f"[error] Get IMU offsets failed rc={rc}")
        return -2
    
    print(f"[info] gx:{gx} gy:{gy} gz:{gz} ax:{ax} ay:{ay} az:{az}")
    
    # Initialize IMU controler
    # delay 1 second before processing events
    rc = imu.init(1, gx, gy, gz, ax, ay, az)
    if rc < 0:
        print(f"[error] ImuControl.init failed rc={rc}")
        return -3
    
    # register static event call backs
    imu.on_update(on_imu_update)
    imu.on_gesture(on_imu_gesture)

    # wait for a while before exiting
    time.sleep(10)

    # Cleanup
    imu.dispose() 
    time.sleep(0.2) 

    return 0

if __name__ == "__main__":
    raise SystemExit(main())
```

## Common tasks

- **Stop Doly service**
- **Get offset values**
- **Initialize**
- **Add event listener**
- **Read state / values**
- **Dispose / cleanup**

## Notes

- **Platform:** Raspberry Pi OS
- **Python:** 3.11
- **Installed on robot:** Yes (preinstalled)

## API reference

See: [API reference](../api/imu_control.md)

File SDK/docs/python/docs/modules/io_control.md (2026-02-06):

# IoControl (Python)

## Import

```python
import doly_helper
```

## Minimal working example

Below is the module’s `example.py` as a starting point.

```python
"""
example.py

It demonstrates:
- Writing IO pin state
- Reading IO pin state

"""

import time
import doly_helper as helper
import doly_io as io

def main():

    # Version
    try:
        print(f"[info] IoControl Version: {io.get_version():.3f}")
    except AttributeError:
        pass

    # *** IMPORTANT *** 
    # Stop doly service if running,
    # otherwise instance of libraries cause conflict	
    if helper.stop_doly_service() < 0: 
        print("[error] Doly service stop failed")
        return -1
    
    # INFORMATION
    print("[info] Before testing, connect IO port 0 and port 1 (pin_0 <-> pin_1).")

    # write pin state => HIGH 
    io_0 = 0 # IO port pin_0
    io.write_pin(1, 0, io.GpioState.High)
    # read IO pin state
    io_1 = 1 # IO port pin_1
    state = io.read_pin(2, io_1);
    print(f"[info] Read Pin:{io_1} State:{state}")

    # write pin state => LOW 
    io.write_pin(1, 0, io.GpioState.Low)
    # read IO pin state
    state = io.read_pin(2, io_1);
    print(f"[info] Read Pin:{io_1} State:{state}")

    return 0

if __name__ == "__main__":
    raise SystemExit(main())
```

## Common tasks

- **Stop Doly service**
- **Read/Write pin state**

## Notes

- **Platform:** Raspberry Pi OS
- **Python:** 3.11
- **Installed on robot:** Yes (preinstalled)

## API reference

See: [API reference](../api/io_control.md)

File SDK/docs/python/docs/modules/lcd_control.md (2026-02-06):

# LcdControl (Python)

## Import

```python
import doly_helper
```

## Minimal working example

Below is the module’s `example.py` as a starting point.

```python
"""
example.py

It demonstrates:
- Initializing the LCD controller
- Writes a full white frame to both displays
- Fills left display blue and right display red
- Cleaning up (dispose)

"""

import time
import doly_helper as helper
import doly_lcd as lcd

def fill_buffer_example():
    # Allocate the exact buffer size required by the LCD
    size = lcd.get_buffer_size()
    buf = bytearray([0xFF]) * size 

    # write_lcd(side, buffer) accepts bytes/bytearray/memoryview/numpy uint8
    r1 = lcd.write_lcd(lcd.LcdSide.Left, buf)
    r2 = lcd.write_lcd(lcd.LcdSide.Right, buf)

    if r1 < 0:
        print("Left LCD write failed!")
    if r2 < 0:
        print("Right LCD write failed!")

    return 0 if (r1 >= 0 and r2 >= 0) else -1

def fill_color_example():
    lcd.lcd_color_fill(lcd.LcdSide.Left, 0, 0, 255)
    lcd.lcd_color_fill(lcd.LcdSide.Right, 255, 0, 0)

def main():

    # Version
    try:
        print(f"[info] LcdControl Version: {lcd.get_version():.3f}")
    except AttributeError:
        pass

    # *** IMPORTANT *** 
    # Stop doly service if running,
    # otherwise instance of libraries cause conflict	
    if helper.stop_doly_service() < 0: 
        print("[error] Doly service stop failed")
        return -1

    # Initialize ToF sensor controler
    rc = lcd.init(lcd.LcdColorDepth.L12BIT)
    if rc != 0:
        print(f"[error] LcdControl.init failed rc={rc}")
        return -2
    
    # brightness 0-10
    lcd.set_brightness(10)

    # read back current depth
    depth = lcd.get_color_depth()
    print(f"[info] Lcd Color Depth: {depth}")

    # Demo 1: fill by buffer
    fill_buffer_example()

    time.sleep(3)

    # Demo 2: fill by color
    fill_color_example()

    # Cleanup
    lcd.dispose()    
    time.sleep(0.2) 

    return 0

if __name__ == "__main__":
    raise SystemExit(main())
```

## Common tasks

- **Stop Doly service**
- **Initialize**
- **Set brightness**
- **Write buffer to LCD(s)**
- **Dispose / cleanup**

## Notes

- **Platform:** Raspberry Pi OS
- **Python:** 3.11
- **Installed on robot:** Yes (preinstalled)

This module uses `/dev/doly_*` devices. Permissions are configured by default; however, if you encounter issues, ensure user permissions are correctly set (see **Troubleshooting → Permissions**).

## API reference

See: [API reference](../api/lcd_control.md)

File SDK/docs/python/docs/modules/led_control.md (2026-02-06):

# LedControl (Python)

## Import

```python
import doly_helper
```

## Minimal working example

Below is the module’s `example.py` as a starting point.

```python
"""
example.py

It demonstrates:
- Initializing the LED controller
- Setting static event callbacks
- Change LEDs with fade effect
- Change LEDs instant
- Cleaning up (dispose)

"""

import time
import doly_helper as helper
import doly_led as led
from doly_color import Color, ColorCode

def on_led_complete(cmd_id: int, side):
    print(f"[info] Led complete id={cmd_id} side={side}")

def on_led_error(cmd_id: int, side, err_type):
    print(f"[info] Led complete id={cmd_id} side={side} error={err_type}")

def main():

    # Version
    try:
        print(f"[info] LedControl Version: {led.get_version():.3f}")
    except AttributeError:
        pass

    # *** IMPORTANT *** 
    # Stop doly service if running,
    # otherwise instance of libraries cause conflict	
    if helper.stop_doly_service() < 0: 
        print("[error] Doly service stop failed")
        return -1

    # Initialize ToF sensor controler
    rc = led.init()
    if rc != 0:
        print(f"[error] LcdControl.init failed rc={rc}")
        return -2
    
    # Register static event listeners if required
    led.on_complete(on_led_complete)
    led.on_error(on_led_error)

    # fade effect example
    activity1 = led.LedActivity()
    activity1.mainColor = Color.from_code(ColorCode.Red)
    activity1.fadeColor = Color.from_code(ColorCode.Blue)
    activity1.fade_time = 2000  # 2 seconds (milliseconds)

    led.process_activity(1, led.LedSide.Both, activity1)
    # Let the activity run for a while on another thread
    time.sleep(2.5)

    # instant color change example
    activity2 = led.LedActivity()
    activity2.mainColor = Color.from_code(ColorCode.Orange)
    activity1.fade_time = 0  

    led.process_activity(2, led.LedSide.Right, activity2)

    # wait activity event completion before dispose
    time.sleep(0.2)

    # Cleanup
    led.dispose()    
    time.sleep(0.2) 

    return 0

if __name__ == "__main__":
    raise SystemExit(main())
```

## Common tasks

- **Stop Doly service**
- **Initialize**
- **Add event listener**
- **Set LED(s) color**
- **Read state / values**
- **Dispose / cleanup**

## Notes

- **Platform:** Raspberry Pi OS
- **Python:** 3.11
- **Installed on robot:** Yes (preinstalled)

## API reference

See: [API reference](../api/led_control.md)

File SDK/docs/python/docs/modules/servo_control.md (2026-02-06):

# ServoControl (Python)

## Import

```python
import doly_helper
```

## Minimal working example

Below is the module’s `example.py` as a starting point.

```python
"""
example.py

It demonstrates:
- Initializing the external servo controller (IO plug servos)
- Setting static event callbacks
- Setting servo position
- Releasing servo hold
- Cleaning up (dispose)

"""

import time
import doly_helper as helper
import doly_servo as servo

def on_servo_abort(id, channel):
	print(f"[info] Servo abort id:{id} channel:{channel}")
     
def on_servo_complete(id, channel):
	print(f"[info] Servo complete id:{id} channel:{channel}")

def on_servo_error(id, channel):
	print(f"[info] Servo error id:{id} channel:{channel}")

def main():

    # Version
    try:
        print(f"[info] ServoControl Version: {servo.get_version():.3f}")
    except AttributeError:
        pass

    # *** IMPORTANT *** 
    # Stop doly service if running,
    # otherwise instance of libraries cause conflict	
    if helper.stop_doly_service() < 0: 
        print("[error] Doly service stop failed")
        return -1
    
    # Initialize servo controler
    rc = servo.init()
    if rc < 0:
        print(f"[error] ServoControl.init failed rc={rc}")
        return -2
    
    # Add static event listeners
    servo.on_complete(on_servo_complete)
    servo.on_abort(on_servo_abort)
    servo.on_error(on_servo_error)
    
    # Initialize sound controler to test sound file
    servo.set_servo(1, servo.ServoId.Servo0, 180, 100, False)
    servo.set_servo(2, servo.ServoId.Servo1, 90, 1, False)

    # wait for to complete
    time.sleep(3)

    # Optional release function; disables servo hold position
    servo.release(servo.ServoId.Servo0)
    servo.release(servo.ServoId.Servo1)

    # Cleanup
    servo.dispose() 
    time.sleep(0.2) 

    return 0

if __name__ == "__main__":
    raise SystemExit(main())
```

## Common tasks

- **Stop Doly service**
- **Initialize**
- **Add event listener**
- **Set servo()s angle**
- **Read state / values**
- **Dispose / cleanup**

## Notes

- **Platform:** Raspberry Pi OS
- **Python:** 3.11
- **Installed on robot:** Yes (preinstalled)

## API reference

See: [API reference](../api/servo_control.md)

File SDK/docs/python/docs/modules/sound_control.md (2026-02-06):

# SoundControl (Python)

## Import

```python
import doly_helper
```

## Minimal working example

Below is the module’s `example.py` as a starting point.

```python
"""
example.py

It demonstrates:
- Initializing the Sound controller
- Registering the static event listener
- Seting volume
- Playin sound
- Cleaning up (dispose)

"""

import time
import doly_helper as helper
import doly_sound as snd

def on_snd_begin(id: int, volume):
    print(f"[info] Sound begin id={id} side={volume:.3f}")

def on_snd_complete(id: int):
    print(f"[info] Sound completed id={id}")

def on_snd_abort(id: int):
    print(f"[info] Sound aborted id={id}")

def on_snd_error(id: int):
    print(f"[error] Sound error id={id}")

def main():

    # Version
    try:
        print(f"[info] LedControl Version: {snd.get_version():.3f}")
    except AttributeError:
        pass

    # *** IMPORTANT *** 
    # Stop doly service if running,
    # otherwise instance of libraries cause conflict	
    if helper.stop_doly_service() < 0: 
        print("[error] Doly service stop failed")
        return -1

    # Initialize sound controler
    rc = snd.init()
    if rc < 0:
        print(f"[error] SoundControl.init failed rc={rc}")
        return -2
    
    # Register static event listeners if required
    snd.on_begin(on_snd_begin)
    snd.on_complete(on_snd_complete)
    snd.on_abort(on_snd_error)
    snd.on_error(on_snd_error)

	# Set volume to 80%
    snd.set_volume(80)

    # Play sound
    rc = snd.play("sound_test.wav", 1) < 0
    if rc < 0:
        print(f"[error] Play failed rc={rc}")
        return -3

    # Wait until done (simple polling example)
    while snd.get_state() != snd.SoundState.Stop:
        time.sleep(0.1)

    # Cleanup
    snd.dispose()    
    time.sleep(0.2) 

    return 0

if __name__ == "__main__":
    raise SystemExit(main())
```

## Common tasks

- **Stop Doly service**
- **Initialize**
- **Add event listener**
- **Play**
- **Read state / values**
- **Dispose / cleanup**

## Notes

- **Platform:** Raspberry Pi OS
- **Python:** 3.11
- **Installed on robot:** Yes (preinstalled)

## API reference

See: [API reference](../api/sound_control.md)

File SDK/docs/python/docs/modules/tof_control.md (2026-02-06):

# TofControl (Python)

## Import

```python
import doly_helper
```

## Minimal working example

Below is the module’s `example.py` as a starting point.

```python
"""
example.py

It demonstrates:
- Initializing the ToF sensor controller
- Registering the static event listeners
- Cleaning up (remove_listener + dispose)

"""

import time
import doly_helper as helper
import doly_tof as tof

# Event returns TofGesture data for both sides.
def on_proximity_gesture(left, right):
    print(f"[info] Gesture event L={left.type} R={right.type}")

# Event returns TofData information for both sides.
def on_proximity_threshold(left, right):
    print(f"[info] Proximity event range L={left.range_mm} R={right.range_mm}")

def main():

    # Version
    try:
        print(f"[info] TofControl Version: {tof.get_version():.3f}")
    except AttributeError:
        pass

    # *** IMPORTANT *** 
    # Stop doly service if running,
    # otherwise instance of libraries cause conflict	
    if helper.stop_doly_service() < 0: 
        print("[error] Doly service stop failed")
        return -1

    # Initialize ToF sensor controler
    rc = tof.init()
    if rc < 0:
        print(f"[error] TofControl.init failed rc={rc}")
        return -2
    
    # Setup continues ToF control with 50ms interval and proximity threshold 40mm (enabled)
    if tof.setup_continuous(50, 40) < 0:    
        print("[error] TofControl setup failed")
        return -3;    

    # Register static event listeners 
    tof.on_proximity_gesture(on_proximity_gesture)
    tof.on_proximity_threshold(on_proximity_threshold)    

    # Run for 20 seconds to test TOF events
    print(f"[info] Run for 20 seconds to test TOF sensor events")
    time.sleep(20) 

    # Stop continuous reading and disable events
    if tof.setup_continuous(0) < 0:    
        print("[error] TofControl setup failed")
        return -4;  

    # Single read example
    sensors = tof.get_sensors_data(); 
    for sensor in sensors:
        print(f"[info] Single Read Sensor[{sensor.side}] Range[{sensor.range_mm}mm] Error[{sensor.error}]")

    # Cleanup     
    tof.dispose()       
    time.sleep(0.2) 

    return 0

if __name__ == "__main__":
    raise SystemExit(main())
```

## Common tasks

- **Stop Doly service**
- **Initialize**
- **Add event listener(optional)**
- **Setup continuous(optional)**
- **Read state / values**
- **Dispose / cleanup**

## Notes

- **Platform:** Raspberry Pi OS
- **Python:** 3.11
- **Installed on robot:** Yes (preinstalled)

## API reference

See: [API reference](../api/tof_control.md)

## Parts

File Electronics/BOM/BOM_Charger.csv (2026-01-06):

ID | Name | Designator | Footprint | Quantity | Manufacturer Part | Manufacturer
1 | 66.5 | R3 | R0603 | 1 | 0603WAF665JT5E | UniOhm
2 | 470K | R4 | R0603 | 1 | 0603WAF4703T5E | UniOhm
3 | NC | R5 | R0603 | 1 | 0603WAF3401T5E | UNI-ROYAL(厚声)
4 | TP_1.5MM | TP+5V | PAD_2.5*5 | 1
5 | TPS2069CDBVR | U10 | SOT-23-5_L3.0-W1.7-P0.95-LS2.8-BR | 1 | TPS2069CDBVR | TI(德州仪器)
6 | DockChargeContact | CONT+,CONT- | DOCK_CONTACT | 2
7 | 1uF | C41,C42 | C0603 | 2 | CL10A105KA8NNNC | SAMSUNG
8 | 22uF | C16 | C0603 | 1 | GRM188R61A226ME15D | MuRata
9 | Pad_3x4_mm | CP+,CP- | PAD_3X4_MM | 2
10 | 1uF | C4 | 0603 | 1 | CL10A105KP8NNNC | SAMSUNG
11 | A1501WR-S-2P | CN_LED | CONN-SMD_A1501WR-S-2P | 1 | A1501WR-S-2P | Changjiang Connectors
12 | 2N7002 | LED_CTRL | SOT-23 | 1 | 2N7002(Silk screen12W) | SK

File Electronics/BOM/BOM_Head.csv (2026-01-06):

ID | Name | Designator | Footprint | Quantity | Manufacturer Part | Manufacturer
1 | NC | LED1,LED2 | LED0603-R-RD_BLUE | 2 | SZYY0603B | Yongyu Photoelectric
2 | NC | R3,R19 | R0603 | 2 | 0603WAJ0102T5E | UniOhm
3 | THD0515-45CL-SN | HEAD_PANEL | FFC-SMD_45P-P0.50_THD0515-45CL-SN | 1 | THD0515-45CL-SN | THD(台华达)
4 | 47kΩ | R7,R15 | R0603 | 2 | RC0603FR-0747KL | YAGEO(国巨)
5 | 100nF | C1,C12,C78 | C0603 | 3 | CL10B104KB8NNNC | SAMSUNG
6 | 10kΩ | R2,R10,R11,R17,R18,R20,R9,R4 | R0603 | 8 | RT0603DRE0710KL | YAGEO
7 | 4.7K | R12,R16 | R0603 | 2 | RC0603FR-074K7L | YAGEO(国巨)
8 | 100kΩ | R14,R21 | R0603 | 2 | 0603WAF1003T5E | UniOhm
9 | MTCH101T-I/OT | U1,U3 | TSOT-23-6_L2.9-W1.6-P0.95-LS2.8-BL | 2 | MTCH101T-I/OT | Microchip Tech
10 | THD0515-12CL-SN | FPNL | FPC-SMD_12P-P0.50_THD0515-12CL-SN | 1 | THD0515-12CL-SN | THD
11 | DLW21SN900SQ2L | L9,L10,L8 | FILTER-SMD_4P-L2.0-W1.2-TL_DLW21H | 3 | DLW21SN900SQ2L | MuRata
12 | TP_1.5MM | TPL1,TPR1 | TP-3.8*1.8 | 2 | Custom Contact | Custom
13 | 1uF | C7,C8,C5,C6,C69,C70,C71,C72,C73,C74,C75,C76,C77,C3,C4 | C0603 | 15 | CL10A105KA8NNNC | SAMSUNG
14 | 2.05 | R8,R5 | R0603 | 2 | AC0603FR-072R05L | YAGEO
15 | 600Ω | L12,L11 | L0603 | 2 | BLM18AG601SN1D | MuRata
16 | ME6211C28M5G | U16,P2V8 | SOT-23-5_L3.0-W1.7-P0.95-LS2.8-BR | 2 | ME6211C28M5G | MICRONE
17 | RT9013-12GB | U17 | SOT-23-5_L3.0-W1.7-P0.95-LS2.8-BR | 1 | RT9013-12GB | RICHTEK
18 | PJT138K_R1_00001 | Q7 | SOT-363_L2.0-W1.3-P0.65-LS2.1-BL | 1 | PJT138K_R1_00001 | PANJIT International
19 | 2kΩ | R53,R54,R55,R56 | R0603 | 4 | 0603WAF2001T5E | UniOhm
20 | 22 | R57 | R0603 | 1 | RC0603FR-0722RL | YAGEO
21 | 24MHz | X2 | OSC-SMD_4P-L3.2-W2.5-BL-1 | 1 | OT322524MJBA4SL | YXC扬兴科技
22 | 1kΩ | R6 | R0603 | 1 | 0603WAJ0102T5E | UniOhm
23 | 2N7002(Silk screen12W) | U4 | SOT-23_L2.9-W1.3-P1.90-LS2.4-BR | 1 | 2N7002(Silk screen12W) | SK
24 | AP2127K-1.8TRG1 | U15 | SOT-23-5_L3.0-W1.7-P0.95-LS2.8-BR | 1 | AP2127K-1.8TRG1 | DIODES
25 | 5055502420 | U2 | CONN-SMD_24P-P0.40_5055502420 | 1 | 5055502420 | null
26 | HDGC1002WV-S-2P | SPKL,SPKR | CONN-SMD_2P-P1.00_HDGC_HDGC1002WV-S-2P | 2 | HDGC1002WV-S-2P | HDGC(华德共创)
27 | 820K | R1,R13 | R0603 | 2 | RC0603FR-07820KL | YAGEO
28 | LCD 1.28" ips round | LCDL,LCDR | LCD 1.28 12PIN ROUND | 2

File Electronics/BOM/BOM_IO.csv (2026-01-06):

ID | Name | Designator | Footprint | Quantity | Manufacturer Part | Manufacturer
1 | THD0515-24CL-SN | IO_PNL | FPC-SMD_24P-P0.50_THD0515-24CL-SN | 1 | THD0515-24CL-SN | THD(台华达)
2 | PZ254V-12-8P | SERVO | HDR-TH_8P-P2.54-V-M-R2-C4-S2.54 | 1 | PZ254V-12-8P | XFCN(兴飞)
3 | 1.0T-4PLTPZ | QWIIC | FPC-SMD_4P-P1.00_1.0T-4PLTPZ | 1 | 1.0T-4PLTPZ | BOOMELE(博穆精密)
4 | HDGC1002WV-S-3P | UART | CONN-SMD_3P-P1.00_HDGC_HDGC1002WV-S-3P | 1 | HDGC1002WV-S-3P | HDGC(华德共创)
5 | 210S-2*6P L=11.6MMGold-plated black | GPIO | HDR-TH_12P-P2.54-V-M-R2-C6-S2.54 | 1 | 210S-2*6P L=11.6MMGold-plated black | Ckmtw
6 | USB-A Vertical 10.5mm | USB | USB-TH_1050570001 | 1 | 1050570001 | Molex

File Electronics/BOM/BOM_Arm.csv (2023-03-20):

ID | Name | Designator | Footprint | Quantity | Manufacturer Part | Manufacturer
1 | THD0515-08CL-SN | ARM | FPC-SMD_8P-P0.50_THD0515-08CL-SN | 1 | THD0515-08CL-SN | THD
2 | 15 | R1,R2 | R0603 | 2 | RC0603FR-0715RL | YAGEO
3 | 66.5 | R3 | R0603 | 1 | 0603WAF665JT5E | UniOhm
4 | LTST-K563BGEW | LED1 | LTST-K563BGEW | 1 | LTST-K563BGEW | Lite-On

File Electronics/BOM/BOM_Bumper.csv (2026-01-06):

ID | Name | Designator | Footprint | Quantity | Manufacturer Part | Manufacturer
1 | 1uF | C5,C10 | C0603 | 2 | CL10A105KA8NNNC | SAMSUNG
2 | 100nF | C4,C50 | C0603 | 2 | CL10B104KB8NNNC | SAMSUNG
3 | ZTS6117H | MICL,MICR | MIC-SMD_4P-L2.8-W1.9-P1.84-TL_ZTS6117 | 2 | ZTS6117H | ZILLTEK(钰太)
4 | VL6180 | TOF_L,TOF_R | VL6180X | 2 | VL6180V1NR/1 | STMicroelectronics
5 | RB521S-30 | D1 | SOD-523_L1.2-W0.8-LS1.6-RD | 1 | RB521S-30 | SK
6 | L2N7002SDW1T1G | Q1 | SOT-363_L2.0-W1.3-P0.65-LS2.1-BL | 1 | L2N7002SDW1T1G | Leshan Radio
7 | 47K | R1,R77 | 0603 | 2 | 0603WAF4702T5E | UniOhm
8 | 2kΩ | R53,R56 | R0603 | 2 | 0603WAF2001T5E | UniOhm
9 | THD0515-12CL-SN | FPNL | FPC-SMD_12P-P0.50_THD0515-12CL-SN | 1 | THD0515-12CL-SN | THD

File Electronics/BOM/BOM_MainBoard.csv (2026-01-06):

ID | Name | Designator | Footprint | Quantity | Manufacturer Part | Manufacturer
1 | NC | LED4 | LED0603-R-RD_BLUE | 1 | SZYY0603B | Yongyu Photoelectric
2 | NC | C64,C65 | C0603 | 2 | CC0603KRX5R8BB684 | YAGEO
3 | NC | R3 | R0603 | 1 | 0603WAF2001T5E | UniOhm
4 | NC | WLED1,WLED2 | LED0603-RD_WHITE | 2 | MHT192WDT-C10 | MEIHUA(美华)
5 | TPS2069CDBVR | U10 | SOT-23-5_L3.0-W1.7-P0.95-LS2.8-BR | 1 | TPS2069CDBVR | TI(德州仪器)
6 | NC | R44 | R0603 | 1 | 0603WAF3401T5E | UNI-ROYAL(厚声)
7 | DCIN_10*8mm | DCIN1 | DCIN_10*8_ML | 1 | Custom Contact | Custom
8 | THD0515-24CL-SN | IO_PNL | FPC-SMD_24P-P0.50_THD0515-24CL-SN | 1 | THD0515-24CL-SN | THD(台华达)
9 | THD0515-08CL-SN | ARM_L1,ARM_R1,DRVL1,DRVR1 | FPC-SMD_8P-P0.50_THD0515-08CL-SN | 4 | THD0515-08CL-SN | THD
10 | GP2S700HCP | BL1,BR1,FL1,FR1 | OPTO-SMD_GP2S700HCP | 4 | GP2S700HCP | Sharp Microelectronics
11 | LMV324DTBR2G | LMV1 | TSSOP-14_L5.0-W4.4-P0.65-LS6.5-BL | 1 | LMV324DTBR2G | ON Semicon
12 | PCA9685PW/Q900,118 | PWM1 | TSSOP-28_L9.7-W4.4-P0.65-LS6.4-BL | 1 | PCA9685PW/Q900,118 | NXP
13 | 1uF | C2,C40,C41,C42,C61,C62,C53,C11,C5,C6,C9,C13,C14,C16,C17 | C0603 | 15 | CL10A105KA8NNNC | SAMSUNG
14 | 15kΩ | R55 | R0603 | 1 | 0603WAF1502T5E | UniOhm
15 | MT9700 | U7,U2 | SOT-23-5_L3.0-W1.7-P0.95-LS2.8-BR | 2 | MT9700 | AEROSEMI
16 | SKSGACE010 | SW1 | SW-SMD_SKSGAAE010 | 1 | SKSGACE010 | ALPS Electric
17 | 1kΩ | R24,R33,R34,R35,R36,R4,R49,R42,R50,R23,R11,R12,R13,R14 | R0603 | 14 | 0603WAJ0102T5E | UniOhm
18 | 2N7002(Silk screen12W) | U9,U19,U14,U8 | SOT-23_L2.9-W1.3-P1.90-LS2.4-BR | 4 | 2N7002(Silk screen12W) | SK
19 | 10uF | C26,C10,C55,C51,C28,C27,C46,C48,C49,C37,C1,C3,C8 | C0603 | 13 | CL10A106KP8NNNC | SAMSUNG
20 | 10kΩ | R25,R26,R27,R28,R9,R37,R20,R21,R16,R17,R43,R48,R45,R57,R2,R10 | R0603 | 16 | RT0603DRE0710KL | YAGEO
21 | 6.49kΩ | R29,R30,R31,R32 | R0603 | 4 | ERJ3EKF6491V | PANASONIC
22 | 2kΩ | R5,R6,R39,R40,R47,R61,R62,R7,R8 | R0603 | 9 | 0603WAF2001T5E | UniOhm
23 | DSK24 K24 | D1 | SOD-123_L2.8-W1.8-LS3.7-RD | 1 | DSK24 K24 | MDD
24 | 100nF | C24,C25,C22,C23,C33,C34,C18,C60,C54,C50,C56,C57,C63,C36,C47,C29,C30,C44,C45,C4,C7,C12,C15 | C0603 | 23 | CL10B104KB8NNNC | SAMSUNG
25 | 100 | R19,R22,R15,R18,R46 | R0603 | 5 | RC0603FR-07100RL | YAGEO
26 | TF-115K | CARD1 | TF-SMD_TF-115K | 1 | TF-115K | XUNPU
27 | LSM6DSRTR | U15 | LGA-14_L3.0-W2.5-P0.50-TL | 1 | LSM6DSRTR | ST(意法半导体)
28 | ADS1015IDGSR | U18 | VSSOP-10_L3.0-W3.0-P0.50-LS4.9-BL | 1 | ADS1015IDGSR | TI(德州仪器)
29 | 18-225/B6R6C-C01/3T | LED | LED-SMD_4P-L1.6-W0.8-BR-RD | 1 | 18-225/B6R6C-C01/3T | EVERLIGHT(亿光)
30 | 470pF | C19,C20,C21,C35 | C0603 | 4 | CL10B471KB8NNNC | SAMSUNG(三星)
31 | THD0515-45CL-SN | HEAD_PANEL1 | FFC-SMD_45P-P0.50_THD0515-45CL-SN | 1 | THD0515-45CL-SN | THD(台华达)
32 | 120Ω | L4,L5,L6,L7 | L0603 | 4 | CBM160808U121T | FH
33 | AP2127K-1.8TRG1 | U21 | SOT-23-5_L3.0-W1.7-P0.95-LS2.8-BR | 1 | AP2127K-1.8TRG1 | DIODES
34 | NC | R64 | R1206 | 1 | 1206W4F200LT5E | UniOhm
35 | 22uF | C58,C59,C79,C81,C80,C31,C32,C38,C39,C43 | C0603 | 10 | CL10A226MQ8NRNC | SAMSUNG
36 | TLV320AIC3110IRHBR | U20 | HVQFN-32_L5.0-W5.0-P0.5-TL-EP3.5 | 1 | TLV320AIC3110IRHBR | TI(德州仪器)
37 | 24MHz | X1 | OSC-SMD_4P-L3.2-W2.5-BL-1 | 1 | OT322524MJBA4SL | YXC扬兴科技
38 | 4.7uH | L3 | IND-SMD_L5.4-W5.2 | 1 | MWSA0503S-4R7MT | Sunlord(顺络)
39 | RP CM4 A | A1 | RP CM4 A | 1 | DF40C-100DS-0.4V(51) | HRS(Hirose)
40 | RP CM4 B | B1 | RP CM4 B | 1 | DF40C-100DS-0.4V(51) | HRS(Hirose)
41 | AP2317A | Q2 | SOT-23-3_L2.9-W1.6-P1.90-LS2.8-BR | 1 | AP2317A | ALLPOWER(铨力)
42 | HDGC1002WV-S-4P | SRV_L,SRV_R | CONN-SMD_4P-P1.00_HDGC_HDGC1002WV-S-4P | 2 | HDGC1002WV-S-4P | HDGC(华德共创)
43 | MT3608 | U16,U17 | SOT-23-6_L2.9-W1.6-P0.95-LS2.8-BL | 2 | MT3608 | 西安航天民芯
44 | 100kΩ | R38,R58,R60,R54 | R0603 | 4 | 0603WAF1003T5E | UniOhm
45 | 732K | R56,R53 | R0603 | 2 | AC0603FR-07732KL | YAGEO
46 | 909K | R59 | R0603 | 1 | CR0603FA9093G | LIZ Elec
47 | HDGC1002WV-S-2P | FAN | CONN-SMD_2P-P1.00_HDGC_HDGC1002WV-S-2P | 1 | HDGC1002WV-S-2P | HDGC(华德共创)
48 | BL1551B | U3 | SC-70-6_L2.1-W1.3-P0.65-LS2.3-BR | 1 | BL1551B | BL(上海贝岭)
49 | FS8205 | Q1 | SOT-23-6_L2.9-W1.6-P0.95-LS2.8-BR | 1 | FS8205 | FORTUNE
50 | FS312F-G | U1 | SOT-23-6_L2.9-W1.6-P0.95-LS2.8-BR | 1 | FS312F-G | FORTUNE
51 | SS34L | D4,D2,D3 | SOD-123_L2.8-W1.8-LS3.7-RD | 3 | SS34L | Guangdong Hottech
52 | 100mΩ | R63 | R1206 | 1 | 1206W4F100LT5E | UniOhm
53 | TP5000-QFN16 | U13 | QFN-16_L4.0-W4.0-P0.65-BL-EP2.2 | 1 | TP5000-QFN16 | TOPPOWER
54 | DRV8837CDSGR | DRV_L1,DRV_R1 | WSON-8_L2.0-W2.0-P0.50-TL-EP | 2 | DRV8837CDSGR | Texas Instruments
55 | PCA9535PW,118 | IO1 | TSSOP-24_L7.8-W4.4-P0.65-LS6.4-BL | 1 | PCA9535PW,118 | NXP Semicon
56 | WAFER-PH2.0-2PWB | H1 | CONN-SMD_2P-P2.00_XUNPU_WAFER-PH2.0-2PWB | 1 | WAFER-PH2.0-2PWB | XUNPU(讯普)
57 | 4.7uH | L13,L2 | IND-SMD_L5.4-W5.2 | 2 | MWSA0518S-4R7MT | Sunlord
58 | MDA5030-1R0M | L1 | IND-SMD_L5.2-W5.2_MS0530-3R3M | 1 | MDA5030-1R0M | KOHERelec(科或)
59 | BSS316NH6327XTSA1 | Q3,Q4 | SOT-23-3_L2.9-W1.6-P1.90-LS2.8-BR | 2 | BSS316NH6327XTSA1 | Infineon
60 | 0.01 | R41 | R1206 | 1 | WW12WR010FTL | Huaxin S&T
61 | INA219AIDR | U4 | SOIC-8_L4.9-W3.9-P1.27-LS6.0-BL | 1 | INA219AIDR | TI
62 | TPS61023DRLR | U5 | SOT-563_L1.6-W1.2-P0.50-LS1.6-BR | 1 | TPS61023DRLR | TI(德州仪器)
63 | AP7361C-33Y5-13 | U6 | SOT-89-5_L4.5-W2.5-P1.50-LS4.5-BR | 1 | AP7361C-33Y5-13 | Diodes Incorporated
64 | MAX16150 | U11 | SOT-23-6_L2.9-W1.7-P0.95-LS2.8-BL | 1 | MAX16150AUT+T | Analog Devices Inc./Maxim Integrated
65 | ATSHA204A-SSHDA-T | U12 | SOIC-8_L4.9-W3.9-P1.27-LS6.0-BL | 1 | ATSHA204A-SSHDA-T | Microchip Tech
66 | 8.45kΩ | R1 | R0603 | 1 | ERJ3EKF8451V | PANASONIC

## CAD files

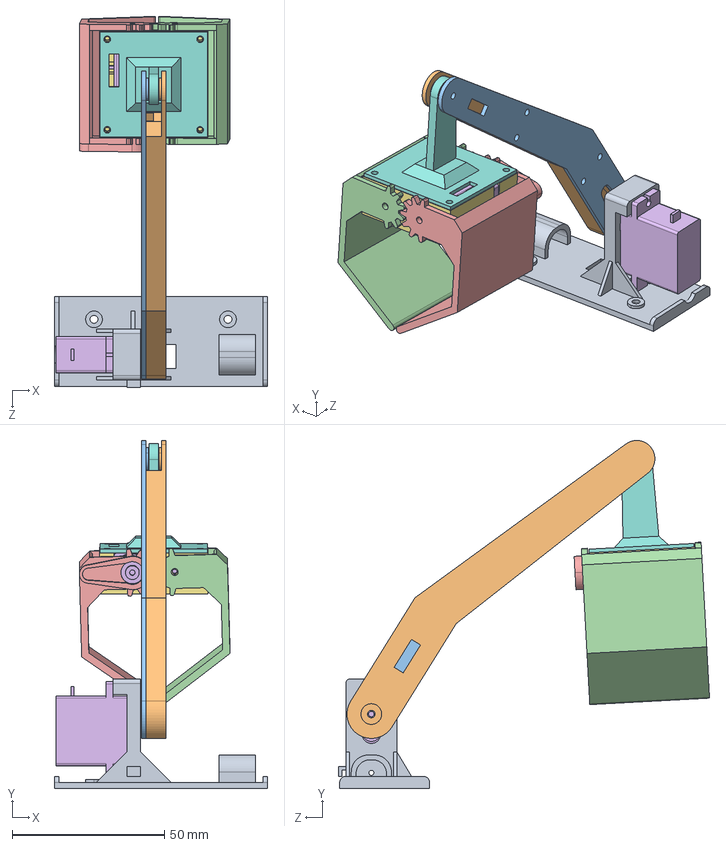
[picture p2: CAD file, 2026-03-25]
Add-ons/powered-addons/crane/assembly/crane_assembly.STEP
70.0 x 114.3 x 121.9 mm
crane_base
crane_arm
crane_arm_cover
gripper_1
gripper_2
servo x 2
servo_base
servo_top

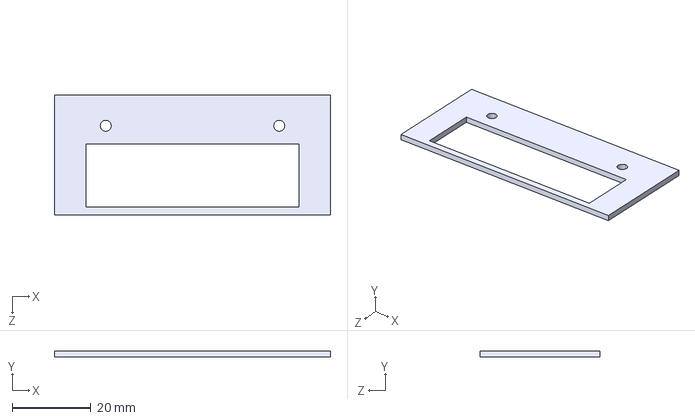
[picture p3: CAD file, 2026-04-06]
Add-ons/helpers/base_template/step/base_template.STEP
70.0 x 1.60 x 30.5 mm

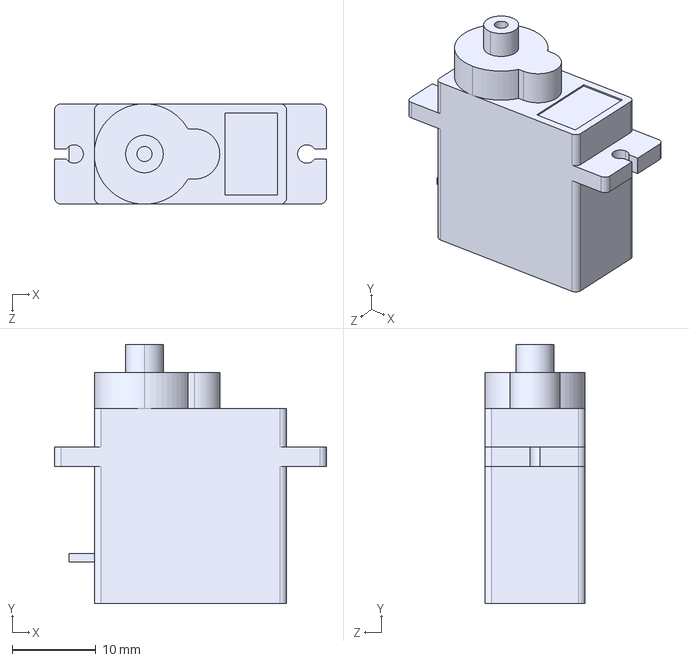
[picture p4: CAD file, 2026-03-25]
Add-ons/helpers/servo/step/servo.STEP
32.5 x 31.0 x 12.0 mm

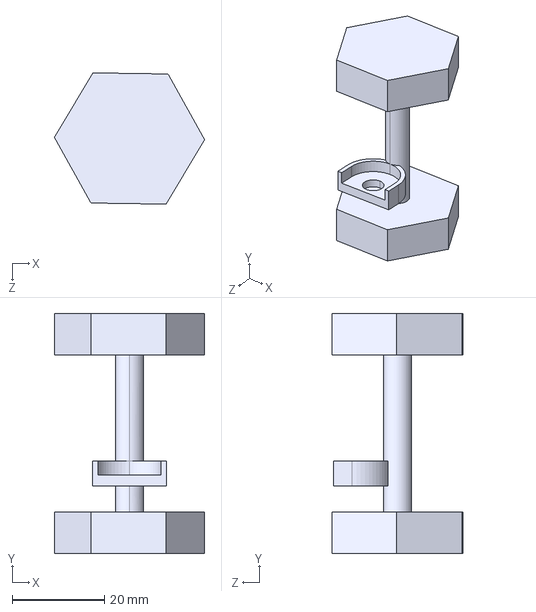
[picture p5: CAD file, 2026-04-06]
Add-ons/passive-addons/dumbbell/step/dumbbell.STEP
32.6 x 52.0 x 28.4 mm

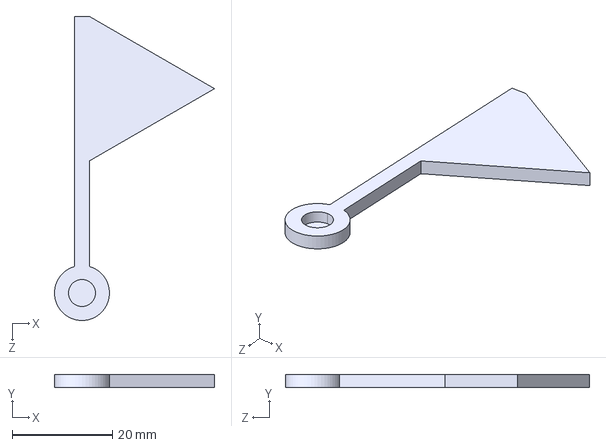
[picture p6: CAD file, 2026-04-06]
Add-ons/passive-addons/flag/step/flag.STEP
32.0 x 2.50 x 60.8 mm

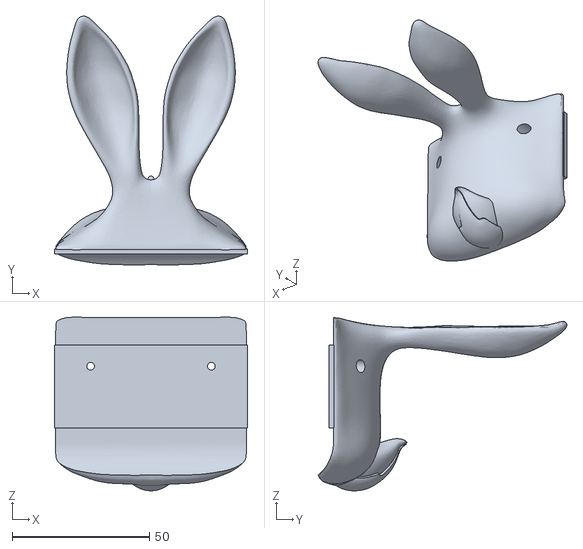
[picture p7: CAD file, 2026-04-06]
Add-ons/passive-addons/rabbit/stl/rabbit.STL
70.4 x 90.8 x 63.4

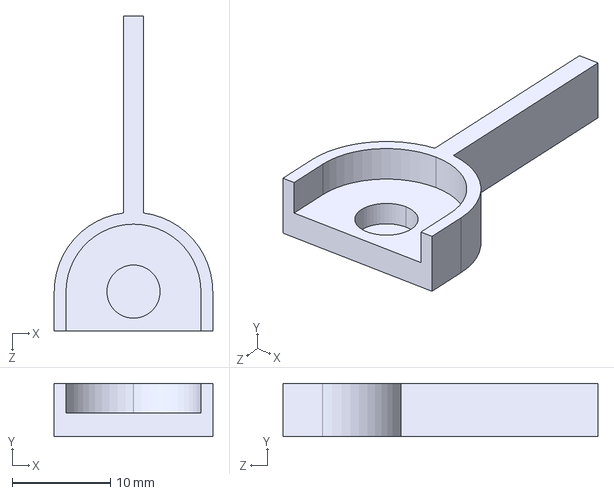
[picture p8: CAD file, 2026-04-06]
Add-ons/passive-addons/sign/step/sign_arm.STEP
16.1 x 5.40 x 32.0 mm

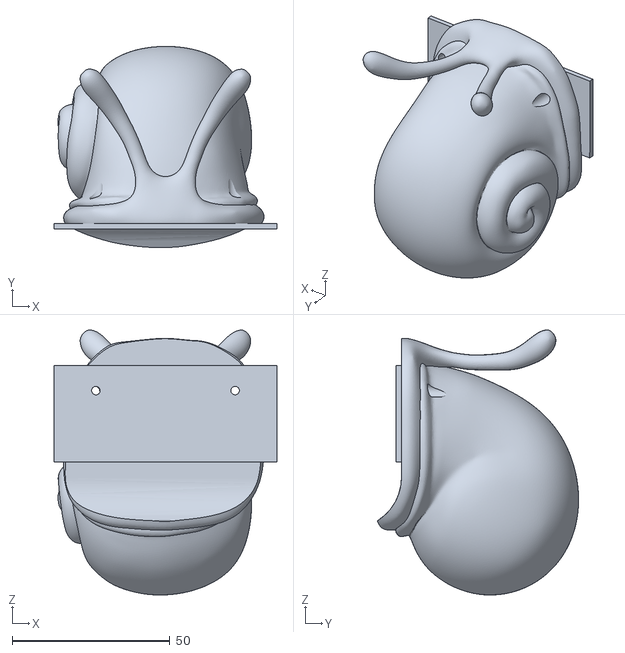
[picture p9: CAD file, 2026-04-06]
Add-ons/passive-addons/snail/stl/snail.STL
70.6 x 63.8 x 84.0

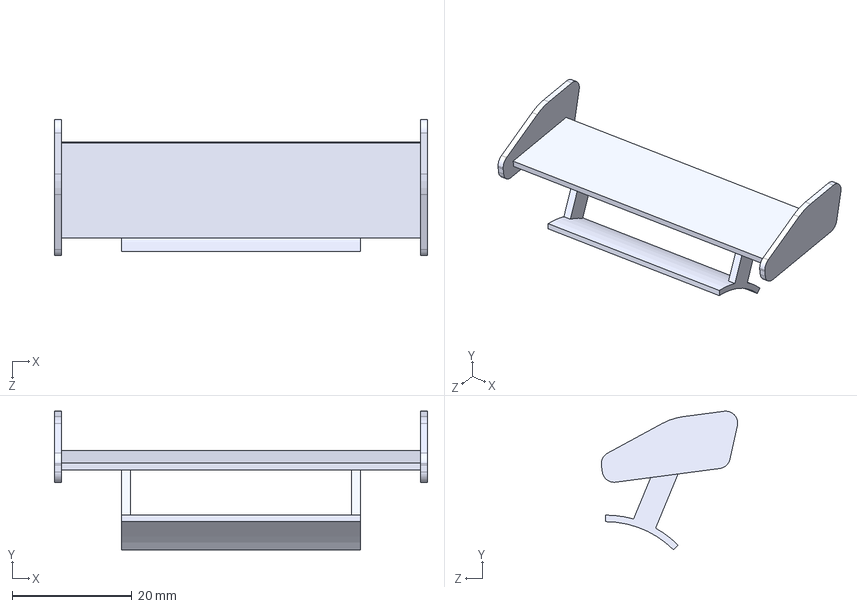
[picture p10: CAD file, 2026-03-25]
Add-ons/passive-addons/spoiler/step/spoiler.STEP
62.4 x 23.2 x 22.8 mm

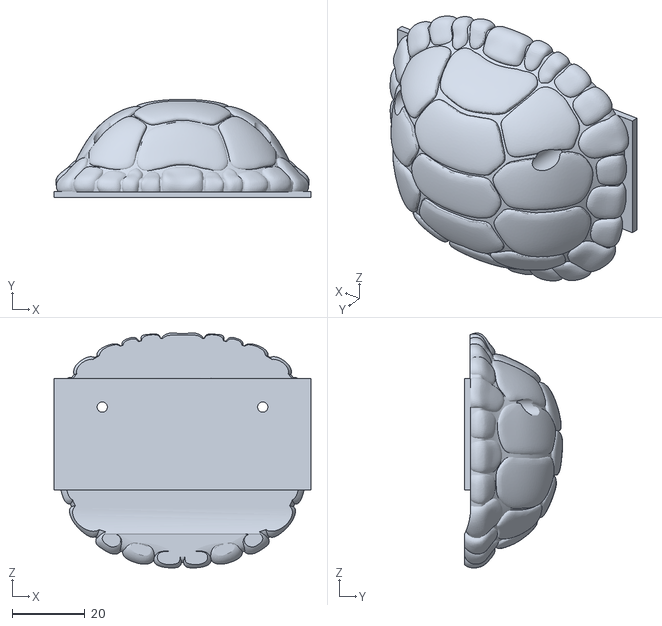
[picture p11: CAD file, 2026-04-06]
Add-ons/passive-addons/turtle/stl/turtle.STL
70.5 x 26.9 x 64.4

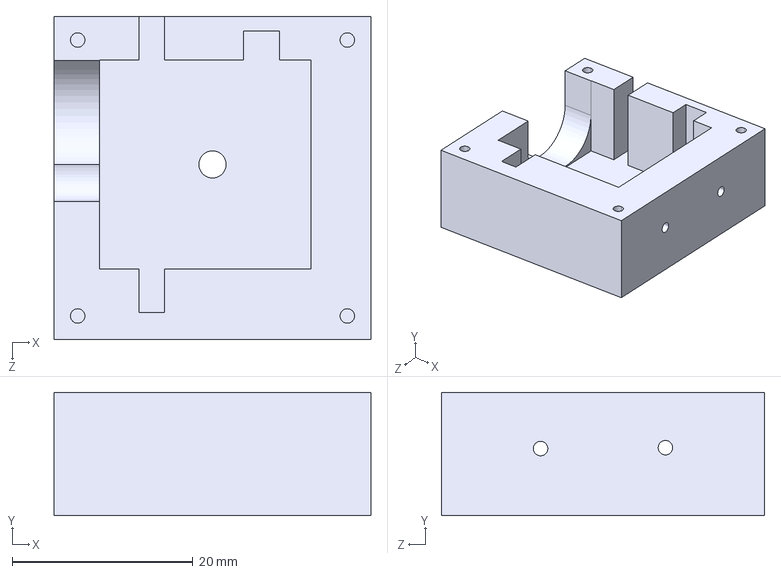
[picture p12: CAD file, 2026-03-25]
Add-ons/powered-addons/crane/step/servo_base.STEP
35.0 x 13.6 x 35.7 mm

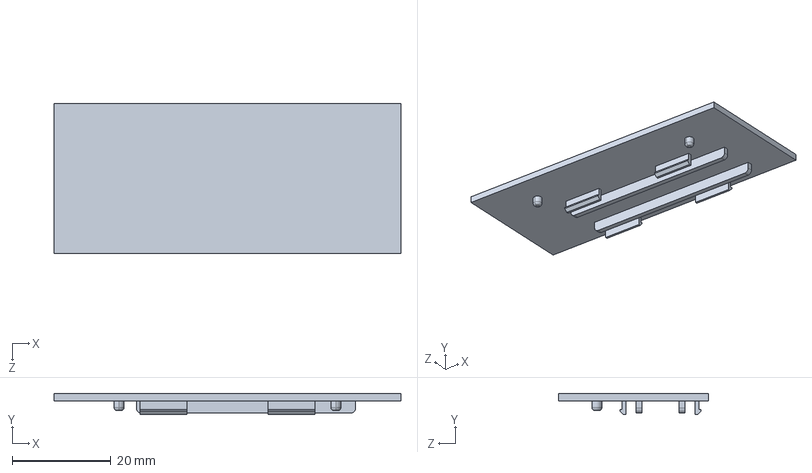
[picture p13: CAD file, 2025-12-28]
Printables/PLA-PETG/IO_cover.STEP
70.4 x 4.30 x 30.4 mm

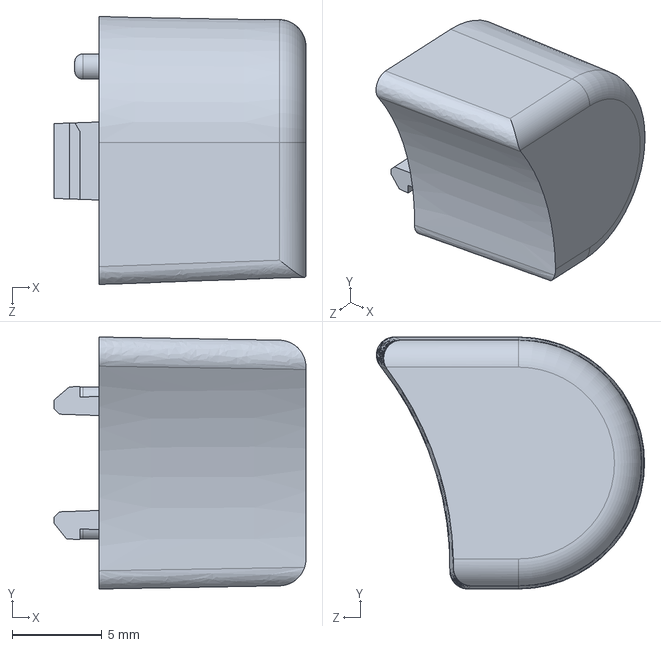
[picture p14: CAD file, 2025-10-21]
Printables/Resin/hand_right.STEP
14.0 x 14.0 x 14.9 mm

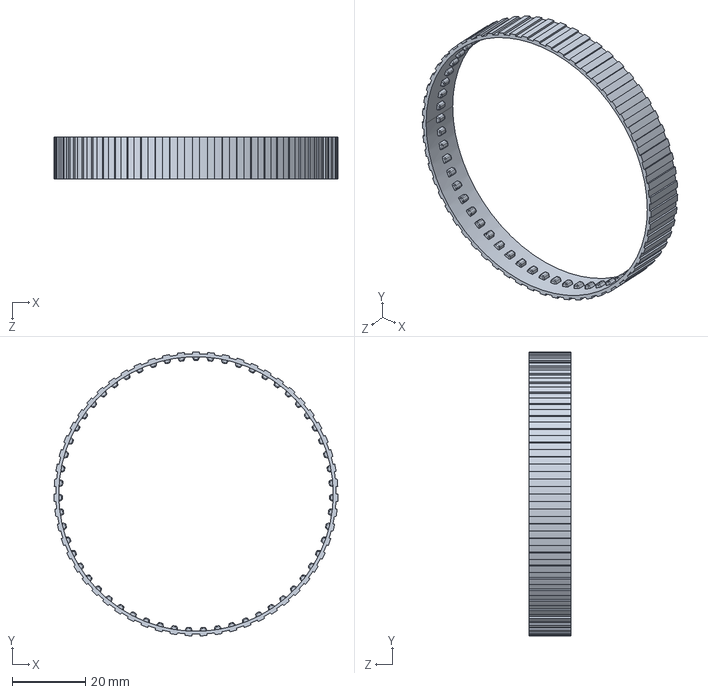
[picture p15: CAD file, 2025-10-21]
Printables/TPU/track_tpu.STEP
77.8 x 77.8 x 11.6 mm

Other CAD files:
Add-ons/passive-addons/sign/step/sign.STEP
Add-ons/powered-addons/crane/step/gripper_1.STEP
Printables/PLA-PETG/body.STEP
Printables/Resin/hand_left.STEP
Add-ons/helpers/base_template/stl/base_template.STL
Add-ons/helpers/servo/stl/servo.STL
Add-ons/passive-addons/dumbbell/stl/dumbbell.STL
Add-ons/passive-addons/flag/stl/flag.STL
Add-ons/passive-addons/sign/stl/sign.STL
Add-ons/passive-addons/sign/stl/sign_arm.STL
Add-ons/passive-addons/spoiler/stl/spoiler.STL
Add-ons/powered-addons/crane/assembly/crane_assembly.x_t
Add-ons/powered-addons/crane/step/crane_arm.STEP
Add-ons/powered-addons/crane/step/crane_arm_cover.STEP
Add-ons/powered-addons/crane/step/crane_base.STEP
Add-ons/powered-addons/crane/step/gripper_2.STEP
Add-ons/powered-addons/crane/step/servo_top.STEP
Add-ons/powered-addons/crane/stl/crane_arm.STL
Add-ons/powered-addons/crane/stl/crane_arm_cover.STL
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

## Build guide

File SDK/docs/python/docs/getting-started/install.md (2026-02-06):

# Install

Doly ships with the Python SDK **preinstalled** on the robot (Raspberry Pi OS, Python 3.11).

## Using the SDK (on the robot)

Most users can start immediately:

- Import the module (e.g., `import doly_arm`)
- Run the module `example.py` from the repository as a starting point
- Build your own script based on the examples

## Developer install (rebuild from source)

If you modify a module’s source code, rebuild and reinstall that module on the robot.

Typical workflow (per module):

1. Edit `source/bindings.cpp`
2. Build a wheel using the module’s `pyproject.toml`
3. Install the wheel on the robot using `pip`

> The exact build commands can differ based on your toolchain and where the C++ libraries live. We document the recommended build steps in each module’s repository and keep this page focused on end-user setup.

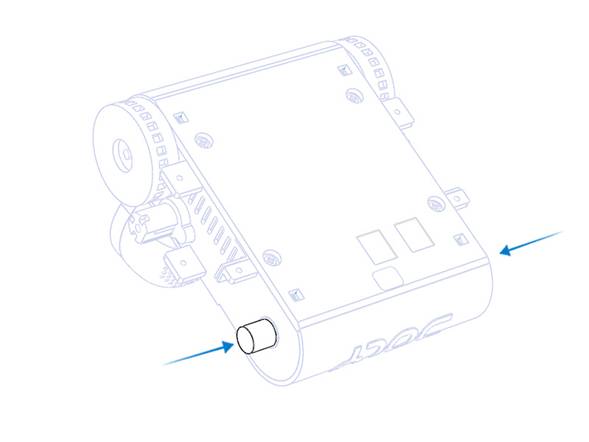
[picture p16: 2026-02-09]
Guide/web/assets/images/image070.jpg

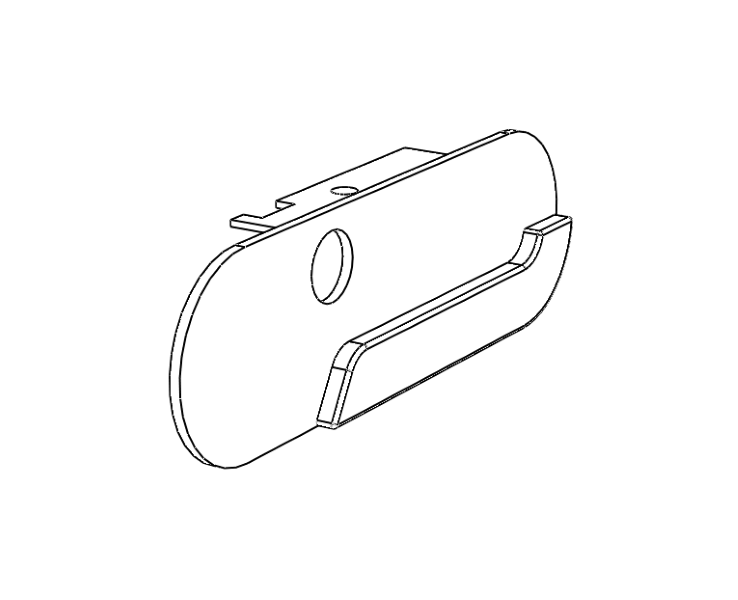
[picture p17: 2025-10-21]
Images/Printables/side_cover_left.png

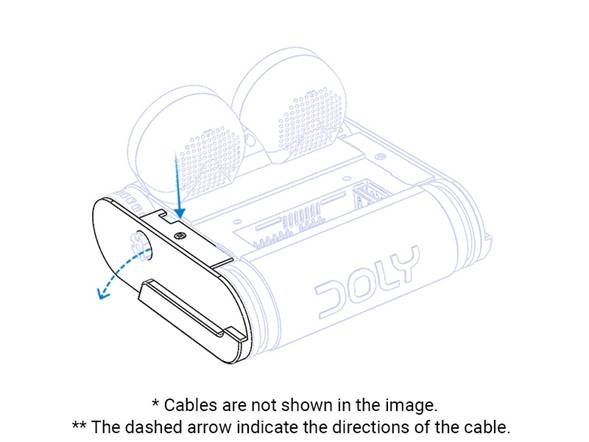
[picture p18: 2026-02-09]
Guide/web/assets/images/image076.jpg

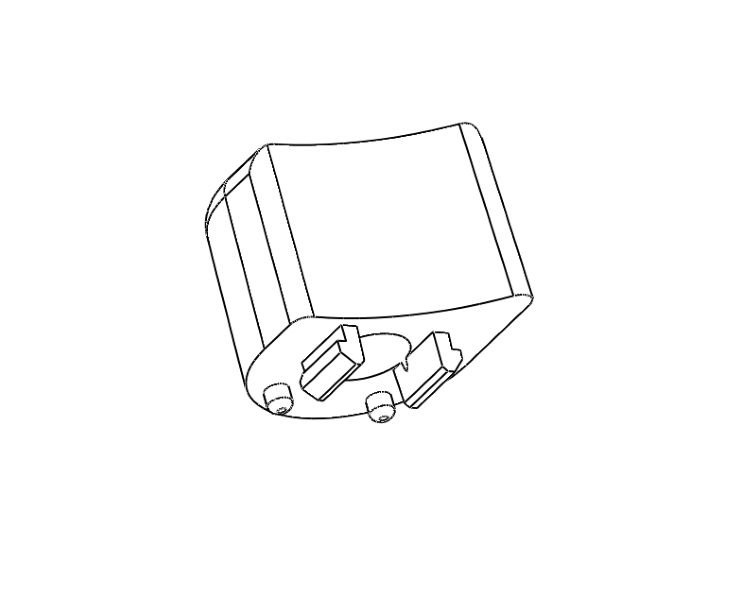
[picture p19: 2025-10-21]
Images/Printables/hand_left.png

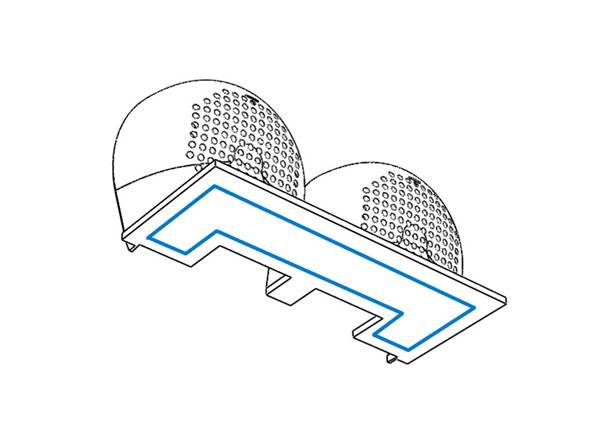
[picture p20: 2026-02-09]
Guide/web/assets/images/image006.jpg

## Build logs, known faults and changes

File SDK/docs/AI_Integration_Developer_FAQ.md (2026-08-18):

# Using Doly with OpenAI, Gemini, and Other AI Models

## Developer FAQ

Doly can be used as a programmable robot platform for custom AI applications. Developers can stop the standard Doly service, run their own application directly on Doly's Raspberry Pi, use the Doly C++ or Python SDK for robot control, and use standard Linux interfaces such as ALSA for audio.

The AI portion of the application can then be implemented by the developer using the AI model or service that fits the project, such as OpenAI, Google Gemini, or another service.

> This FAQ describes custom developer use. It does not mean that every AI provider has an official Doly integration.

Useful starting points:

- [Doly Developer page](https://doly.ai/developer/)
- [DOLY-DIY GitHub repository](https://github.com/robotdoly/DOLY-DIY)
- [C++ SDK documentation](https://robotdoly.github.io/DOLY-DIY/cpp/)
- [Python SDK documentation](https://robotdoly.github.io/DOLY-DIY/python/)

---

### Can I use Doly with OpenAI, Gemini, or another AI model?

Yes. You can run your own C++ or Python application directly on Doly and build the AI integration inside that application.

Doly's SDK can handle robot functions such as movement, camera access, sensors, eyes/displays, LEDs, sound, and other hardware, while your application handles communication with the AI model or service you choose.

The AI provider does not need an official Doly integration. Your application can act as the integration layer between Doly and the provider's API.

See the [Doly Developer page](https://doly.ai/developer/) and [DOLY-DIY SDK](https://github.com/robotdoly/DOLY-DIY/tree/main/SDK).

---

### Do I have to use Doly's default personality or software?

No. You can stop Doly's standard service and run your own application instead.

The official SDK examples stop the Doly service before directly using Doly libraries because running multiple instances of the same hardware-control libraries can cause conflicts. For example, see the [BatteryControl C++ example](https://github.com/robotdoly/DOLY-DIY/blob/main/SDK/examples/cpp/BatteryControl/main.cpp).

You can also configure your own application as a normal Linux service so that it starts automatically when Doly boots.

---

### Does my custom AI application need the Doly mobile app or other service? Can it operate entirely offline?

No for local robot control. A custom application can control Doly locally without depending on the Doly mobile app or other services.

Doly can operate fully offline, if your own application uses an external cloud service, such as an online AI model, that part of the application will require whatever internet connection the selected provider requires. Internet access can also be useful for optional Doly functions such as software updates and online utilities, like weather forecats, but it is not required for a custom local-control application.

See the [Doly Support FAQ](https://doly.ai/support/) and [Doly Developer page](https://doly.ai/developer/).

---

### Can a C++ or Python application continuously access Doly's 8 MP camera?

Yes. The Doly C++ and Python camera interfaces provide direct access to captured frames, including continuous video-frame access. A custom application can process those frames locally or send selected image/video data through its own networking or AI pipeline without using the official Doly application.

The published Doly camera examples demonstrate both still-image capture and continuous video-frame capture:

- [C++ camera example](https://github.com/robotdoly/DOLY-DIY/blob/main/SDK/examples/cpp/Camera/main.cpp)
- [Python camera example](https://github.com/robotdoly/DOLY-DIY/blob/main/SDK/examples/python/Camera/example.py)

Doly uses the **Sony IMX219** 8 MP image sensor, the same sensor family used by the Raspberry Pi Camera Module V2.

Actual usable resolution and frame rate also depend on processing load, image conversion, encoding, networking, and the Raspberry Pi CM4 configuration. Developers should test the selected mode under their real workload rather than assume the sensor's maximum mode is the best streaming setting.

For sensor-mode details, see the [Raspberry Pi Camera V2 sensor-mode documentation](https://picamera.readthedocs.io/en/release-1.13/fov.html#sensor-modes).

---

### Can I access the onboard microphones directly?

Yes. With the Doly service stopped, the onboard microphones can be accessed through ALSA or an ALSA-based library.

A custom application can continuously capture and process raw microphone audio. This allows developers to use their own speech recognition, wake-word, voice-processing, recording, or AI audio pipeline.

---

### Can microphone capture run while I control other parts of Doly?

Yes.

Doly libraries/APIs can operate on different threads. A custom application can capture microphone audio while also using Doly APIs for functions such as the camera, drive system, arms, eyes/displays, LEDs, and sensors.

As with any multithreaded application, the developer is responsible for synchronization and for avoiding conflicting access to the same hardware resource.

---

### Can Doly record from the microphones while playing audio through the speakers?

Yes. Full-duplex audio operation is possible.

A custom application can capture microphone audio while simultaneously playing arbitrary audio through Doly's speakers.

For conversational applications, developers may also need acoustic echo cancellation and noise processing so that speaker output is not interpreted as new microphone input.

---

### Does Doly have hardware Acoustic Echo Cancellation (AEC)?

No. Doly uses the **Texas Instruments TLV320AIC3110** audio codec. It provides audio ADC/DAC, microphone input functions, speaker amplification, filtering, automatic gain control, and other audio-processing features, but it does not provide a dedicated on-chip Acoustic Echo Cancellation function.

Doly's standard software uses third-party software libraries for acoustic echo cancellation and noise processing, but those libraries are not currently exposed through the Doly SDK.

For a custom application, developers can select their own software AEC and noise-processing solution.

See the [Texas Instruments TLV320AIC3110 product documentation](https://www.ti.com/product/TLV320AIC3110) and Doly's [electronics schematics](https://github.com/robotdoly/DOLY-DIY/tree/main/Electronics/Schematic).

---

### Can I use my own speech recognition, TTS, or voice system?

Yes.

After disabling the standard Doly service, you can use your own audio, speech-recognition, wake-word, text-to-speech, or voice-processing solution.

You are not required to use Doly's built-in TTS system for a custom application.

---

### Can different Doly functions run at the same time?

Yes.

The libraries/APIs can be used on different threads within a custom application, allowing an AI program to listen, see, process sensor information, and control robot functions concurrently.

Developers should still coordinate access when multiple tasks use the same device or library resource at the same time.

---

### Can I continuously run my own application on Doly?

Yes.

Doly runs Raspberry Pi OS / Debian Linux on its Raspberry Pi CM4. You can disable Doly's standard service and configure your own application or Linux service to start automatically at boot.

---

### Can Doly charge while my custom software is running?

Yes.

Charging is controlled at the hardware level and does not depend on the standard Doly application running.

Doly can remain physically docked and charge normally while the standard Doly service is stopped and your custom C++ or Python application continues running.

---

### Can custom software read Doly's battery level, charging state, and docking status?

**Battery capacity:** Yes. Battery capacity can be read directly through the Doly SDK. The C++ [`BatteryControl` example](https://github.com/robotdoly/DOLY-DIY/blob/main/SDK/examples/cpp/BatteryControl/main.cpp) demonstrates reading the current percentage with `BatteryControl::getCapacity()`.

**Charging state and docking status:** The current `BatteryControl` library does not expose these as direct SDK status fields.

Doly uses the **Texas Instruments INA219** bidirectional current/power monitor. Doly's standard software determines charging state from the direction of battery current using averaged INA219 readings. In Doly's hardware/current convention, a positive average current indicates that the battery is charging, and Doly treats that as being on the charging dock.

A custom application can implement similar logic by reading the INA219 directly. This is an inferred charging/dock state rather than a dedicated docking-state field in the current `BatteryControl` API.

The INA219 supports bidirectional current measurement over I2C. See the [Texas Instruments INA219 documentation](https://www.ti.com/product/INA219) and the [Doly Community battery discussion](https://community.doly.ai/public/d/34-doly-battery-level-via-sdk/3).

---

### Can I inspect Doly's electronics and hardware interfaces?

Yes.

Doly's electronics schematics and other hardware design files are published in the DOLY-DIY GitHub repository. They are useful for developers who need to understand the underlying sensors, motor drivers, audio hardware, expansion interfaces, power rails, and board connections.

See the [Doly Electronics directory](https://github.com/robotdoly/DOLY-DIY/tree/main/Electronics) and [schematics](https://github.com/robotdoly/DOLY-DIY/tree/main/Electronics/Schematic).

---

### Can I connect additional hardware such as USB LiDAR, a depth camera, microphone array, or other sensors?

Yes. Doly exposes hardware expansion interfaces for custom devices and sensors.

Available expansion interfaces include:

- 6 GPIO pins
- Qwiic / I2C
- UART
- USB
- 2 servo/PWM outputs
- 2 analog inputs associated with the servo channels

The two analog inputs are normally used by Doly's servo system for servo-position feedback. If the corresponding servo channel is not being used through the ServoControl SDK, the analog input can be repurposed as an independent analog input for a custom project.

The analog inputs are separate from the six digital GPIO pins. The current public `IoControl` API documents digital GPIO read/write for pins 0-5; it does not currently expose those servo analog lines as generic `IoControl` analog-read functions.

For power, the shared **5 V user supply supports 1.5 A continuous current and up to 2.15 A peak current**. The peak figure should not be treated as a continuous operating budget. When adding devices such as LiDAR, depth cameras, microphone arrays, servos, or other USB/peripheral hardware, developers should total the expected current consumption and leave appropriate operating margin.

For pinouts, power rails, and electrical details, see:

- [Doly IO schematic](https://github.com/robotdoly/DOLY-DIY/blob/main/Electronics/Schematic/Schematic_IO.pdf)
- [Doly Main Board schematic](https://github.com/robotdoly/DOLY-DIY/blob/main/Electronics/Schematic/Schematic_MainBoard.pdf)
- [Doly Developer page](https://doly.ai/developer/)
- [IoControl public header](https://github.com/robotdoly/DOLY-DIY/blob/main/SDK/include/IoControl.h)
- [ServoControl public header](https://github.com/robotdoly/DOLY-DIY/blob/main/SDK/include/ServoControl.h)

---

### Which I2C buses and device addresses are used inside Doly, and which bus should I use for custom I2C hardware?

Doly uses multiple I2C buses so that different groups of internal hardware are separated.

The current Doly bus map is:

| Linux I2C bus | Doly devices | I2C address |
|---|---|---|
| `/dev/i2c-6` | 2 × ST VL6180X Time-of-Flight sensors | `0x29` and `0x30` after initialization |
| `/dev/i2c-6` | User / Qwiic I2C expansion | Address depends on the connected device |
| `/dev/i2c-3` | NXP PCA9535 GPIO expander | `0x20` |
| `/dev/i2c-3` | NXP PCA9685 PWM controller | `0x40` |
| `/dev/i2c-3` | TI INA219 current/power monitor | `0x41` |
| `/dev/i2c-1` | Texas Instruments TLV320AIC3110 audio codec | `0x18` |
| `/dev/i2c-1` | ST LSM6DSR 6-axis IMU | `0x6A` |
| `/dev/i2c-1` | Texas Instruments ADS1015 ADC | `0x48` |
| `/dev/i2c-0` | Sony IMX219 camera control | Managed by the Raspberry Pi camera/GPU subsystem |

For custom I2C sensors or other expansion hardware, **`/dev/i2c-6` is the intended user-accessible I2C/Qwiic bus**. Developers should make sure that a new device does not conflict with an address already used on that bus.

The two VL6180X ToF sensors have the same default I2C address (`0x29`). During Doly initialization, one sensor is reassigned to `0x30` so that both sensors can operate on the same I2C bus.

The other I2C buses are used by Doly's internal hardware. In particular, `/dev/i2c-0` is used for camera control by the Raspberry Pi camera/GPU subsystem and should not be treated as the normal user expansion bus.

Hardware references:

- [Doly Main Board BOM](https://github.com/robotdoly/DOLY-DIY/blob/main/Electronics/BOM/BOM_MainBoard.csv)
- [Doly Main Board schematic](https://github.com/robotdoly/DOLY-DIY/blob/main/Electronics/Schematic/Schematic_MainBoard.pdf)
- [Doly IO schematic](https://github.com/robotdoly/DOLY-DIY/blob/main/Electronics/Schematic/Schematic_IO.pdf)
- [ST VL6180X](https://www.st.com/en/imaging-and-photonics-solutions/vl6180x.html)
- [NXP PCA9535](https://www.nxp.com/products/interfaces/ic-spi-i3c-interface-devices/general-purpose-i-o-gpio/16-bit-ic-bus-and-smbus-low-power-i-o-port-with-interrupt:PCA9535_PCA95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)
- [NXP PCA9685](https://www.nxp.com/products/power-drivers/lighting-driver-and-controller-ics/led-drivers/16-channel-12-bit-pwm-fm-plus-ic-bus-led-driver:PCA9685)
- [Texas Instruments INA219](https://www.ti.com/product/INA219)
- [ST LSM6DSR](https://www.st.com/en/mems-and-sensors/lsm6dsr.html)
- [Texas Instruments ADS1015](https://www.ti.com/product/ADS1015)
- [Texas Instruments TLV320AIC3110](https://www.ti.com/product/TLV320AIC3110)

---

### What might a custom AI application look like?

The simplest way to think about it is that **your custom Python or C++ application sits in the middle**.

It talks to Doly's hardware through the Doly SDK and standard Linux interfaces such as ALSA, and it talks to an AI service such as OpenAI or Gemini through that service's API.

```text
Doly microphone / camera / sensors
              ↓
      Your custom application
          (Python / C++)
              ↓
       OpenAI / Gemini API
              ↓
      Your custom application
              ↓
Doly speakers / eyes / arms / motors
```

For example, Doly can hear a question through its microphones, your application can process the audio locally or send audio/text to an AI service, receive the response, and then use Doly's speakers, eyes, arms, LEDs, or motors to react.

The same architecture can also be completely local. Instead of a cloud AI service, the custom application can communicate with software running locally on Doly or another computer on the LAN.

This is only one possible design. Developers are free to build the AI, networking, audio, and robot-control flow that fits their application.

---

For implementation details, see the Doly SDK documentation, examples, electronics schematics, and community discussions linked above.

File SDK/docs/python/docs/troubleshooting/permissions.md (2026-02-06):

# Permissions

Some modules talk to Linux device nodes (for example, `/dev/doly_lcd`) or sysfs entries.  
If a module works as **root** but not as a **user**, it is usually a permissions problem. We have already added the `doly` user to the custom `doly` group. If you plan to add a new user to your system to interact with Linux device nodes, please follow the instructions below.

## Recommended approach

- Use **udev rules** to assign a group and permissions to Doly devices
- Add your user to the appropriate group (often `video`, `dialout`, or a custom `doly` group)

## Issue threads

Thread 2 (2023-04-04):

why note readme?

Ming-XF, 2023-04-04:

Ming-XF, 2023-04-04:
misspelling！Why is there no Readme？

robotdoly, 2023-04-04:
As you know this is an ongoing project and documentation takes time. My focus is finishing the project. For now the most effective I have is located at https://www.hackster.io/robotdoly/open-doly-more-than-a-robot-d182c6
If you want to collaborate, that would be incredibly helpful. Thanks

Closed 2023-04-04.

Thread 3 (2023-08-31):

about MAX16150

micele00l, 2023-08-31:
Hello, I found MAX16150 in the BOM_MotherBoard. May I ask if it can be replaced with other cheaper models? Could you please help explain the function of this chip?

robotdoly, 2023-08-31:
@micele00l MAX16150 is pushbutton On/Off Controller. It controls the main power for device. If you have a suggestion for alternative, just let me know. Thanks,

Closed 2023-09-25.

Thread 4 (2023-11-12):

Design files?

samuk, 2023-11-12:
Hi Nice project!

I see you have some Gerbers published, do you intend to publish the design files too so that you can use the OSHW logo etc?

I guess you're aware of this project https://www.pcbway.com/project/shareproject/Pi_MX8M_Plus_SoM_e3fe3cd9.html so an Open hardware CM4 should be available soon.

robotdoly, 2023-11-12:
Hi there, thanks for your interest. I am planning to publish design files asap. Good to hear a new RPi CM4 compatible board is coming 👍

samuk, 2023-11-12:
Great, do you plan to use a licence that complies with https://www.oshwa.org/definition?

robotdoly, 2023-11-13:
Not today 👍

samuk, 2023-11-13:
Tomorrow?

samuk, 2023-11-16:
I'm unclear why you have closed this issue as 'completed' when the issue is not complete?

I also notice you've deleted my comments on Twitter that draw attention to the lack of design files.

If you don't want to be an open hardware project then that is fine, you're under no obligation to release design files.

I do think in that case you should stop describing this project as 'Open Hardware' as that is clearly not the case.

robotdoly, 2023-11-16:
Regarding the issue being marked as 'completed,' I acknowledge that this was done prematurely. As this project is still in development, there are elements, including the sharing of design files, that are yet to be finalized. This is a beta test section just for a few friends! Please don't take it serious.

Concerning your comments on Twitter, I opted to hide them because they seemed to accuse me of not fulfilling a commitment that has not yet come due. As stated on my website's open-source section at [doly.ai/open-source](https://doly.ai/opensource/),  is clearly saying as 'coming soon.' I am committed to being transparent and upholding my promises, but it's important to note that this is a future endeavor, not a current omission. I am a bit perplexed by the aggressive tone in your approach regarding this matter, especially since I have clearly communicated my intentions on my website.

I understand your point about the term 'Open Hardware.' I want to clarify that I am not using this in the strict sense of Open Source Hardware (OSHW), which has specific criteria including the release of design files. The plan to release these files is still in place, but as a solo maker, it takes time to prepare these files for public release.

Your feedback is essential, and I am taking it seriously. Going forward, I will strive to communicate more clearly to avoid any misunderstandings. I appreciate your patience and understanding as I navigate the complexities of bringing this project to fruition.

If you have further questions or need additional clarification, please feel free to reach out.

samuk, 2023-11-16:
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

I do appreciate it takes a bit of time to upload files: https://github.com/rosmo-robot honestly it's a few seconds to export from your EDA program, a few seconds to upload it to Github. Documentation obviously takes longer.

The simple solution is for you to stop using the term 'open hardware' until your hardware is in fact open hardware.

I was irritated by your marketing because I got quite excited about your project, shared it on various Discord channels and networks I'm on, I even started work on a Mikroe expansion header for the back of your bot. At that point I realised you weren't actually a open hardware project at all.

It wasted my time and made me feel stupid. That's why I'm irritated.

robotdoly, 2023-11-16:
Thank you for reaching out and sharing your perspective. I deeply appreciate your enthusiasm for the project and am sorry for any frustration or inconvenience caused.

Regarding the upload of design files, I want to reassure you that it is a priority, and I will be uploading them as soon as possible. However, as I have mentioned before, preparing these files for public use, ensuring their accuracy and completeness, does take time. It is not about export and upload, there are some points to that have to be revised.

I would like to clarify that I am not withholding information; if you need specific details or files, I am more than willing to share them with you directly. This is not a secret nor a significant issue. In fact, all schematics have already been uploaded.

I am dedicated to ensuring that this project meets the expectations associated with the term 'open hardware,' while not strictly adhering to the requirements set by the Open Source Hardware Association (OSHW). The OSHWA license has a distinct approach, particularly concerning commercial usage. Meanwhile, I request that you kindly disregard the current state of the repository.

Your support and the work you've begun, like the development of the Mikroe expansion header, are incredibly valuable. I am genuinely excited about the possibility of collaborating and incorporating your contributions into the project.

Once again, I apologize for any misunderstanding and the impact it has had. Your feedback is crucial, and I am committed to improving our communication and delivering on the project's promises.

Please feel free to reach out if you have any more concerns, need specific files, or have suggestions. Your ongoing support and understanding mean a lot to me.

samuk, 2024-01-15:
Any news on when you're going to publish these files?

robotdoly, 2024-01-16:
Let me share in a minute. As I mentioned before, still no documentation.

robotdoly, 2024-01-16:
I placed the missing files under PCB folder. You can import them via EasyEDA.

PCB_PCB_Doly_CE_2302.json
PCB_PCB_Doly_CE_Bumper_2210.json
PCB_PCB_Doly_CE_Head_2212.json
PCB_PCB_Encoder 0922.json
PCB_Doly_Arm.json
SCH_DOLY_CE_ARM.json
SCH_Doly_CE_Bumper_v1.2210.json
SCH_Doly_CE_Encoder_0922.json
SCH_Doly_CE_Head_v1.2212.json
SCH_Doly_CE_v1.2302.json

Closed 2023-11-12.

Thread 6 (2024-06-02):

about SDK

renhaiyizhigou, 2024-06-02:
Hello, thank you for contributing. Will this project consider providing SDK files?

robotdoly, 2024-06-03:
Thank you for your interest in the Doly project. I am currently working on an SDK, but our main focus at the moment is updating the hardware. We are adding some new features and making minor fixes. Probably, it will be ready at late 2024.

Closed 2024-06-03.

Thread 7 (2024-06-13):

Missing files

sai021, 2024-06-13:
Thanks for making the repository opensource. I found your instructions on ordering the parts from JLCPCB. Perfect.
Only thing is i am unable to find the pcb files for the charger.
can you upload them please.

robotdoly, 2024-06-13:
Hi @sai021 , thanks for your interest in project Doly. I checked the repository and I believe the only missing file is EasyEDA project file about charger. I uploaded it. If there are any missing files, just let me know.

sai021, 2024-06-13:
Hi @robotdoly the only 2 more files missing: the PCB_PCB_Doly_CE_Charger_.json and PCB_Doly_DIY_Charger_.html.

This project is so amazing.
Do you have any plans to sell the DIY kit (with boards, displays and motors).
It will be very interesting to see these bots interacting with each other.
The io port is just genius.

robotdoly, 2024-06-14:
Thanks @sai021, I uploaded them as well.

Thanks for your kind words. Yes, actually I am offering pre-orders for DIY kit. The DIY kits will come with advanced software. I am aware that making some parts is not easy, especially metal parts. The DIY kit will include all the parts, including customized LCD, servos, and others. You just need to 3D print body parts and assemble the robot.  You can reach the DIY kit pre-order page with the following link.

https://www.indiegogo.com/projects/2917355/x/37158257?secret_perk_token=c08a2f22

I am positive the community will make awesome add-ons for Doly with support of this IO port.

Thanks for your support.

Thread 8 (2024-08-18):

Coordinate Files

mjzxssx, 2024-08-18:
I am very interested in your project and am trying to restore it using SMT automatic patching technology. However, I found that there seems to be no coordinate file in the project warehouse. May I ask if you can provide the coordinate file?

robotdoly, 2024-08-22:
Hi @mjzxssx, I'm not sure what exactly you need. What is this coordinate file? Are you asking for pick and place files? The DIY Doly PCB  files are shared in the PCB folder, which includes the EasyEDA source files. If the file you're asking for is supported by EasyEDA, you can import the project and then export whatever you need. Is there anything that I can help?

846kami, 2025-05-27:
Great project. I can't see the IO Board JSON file. I'm going to make a pick&place file.

robotdoly, 2025-05-27:
Hello  @846kami, thanks for your interest. I realized that after your message. I uploaded, please check. Thanks.

846kami, 2025-05-28:
Thank you so much for your reply. Also, I checked the IO module  schematic JSON file well. I don't have IO module PCB JSON file, can you upload it?

846kami, 2025-05-28:
I'm going to make the IO module BOM file and the coordinate file of the rest of the modules (PICK & PLACE FILE). And thank you again for the fun and wonderful project.

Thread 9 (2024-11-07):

Unable to Link Static Libraries to Shared Library Due to Missing `-fPIC`

jonyhunter, 2024-11-07:
Dear Doly DIY Team, Thank you for developing and maintaining this excellent open-source project.

I am a Java developer, and because of my appreciation for Doly, I hope it can be used more widely by Java developers. To achieve this, I have invested a significant amount of time implementing JNI to bridge Java with the hardware libraries. However, I have encountered an unresolved issue: the four static libraries you provide—`libGpio.a`, `libLcdControl.a`, `libServoMotor.a`, and `libTimer.a`—were not compiled with the `-fPIC` option. This prevents me from linking them into a shared library, as shared libraries require Position-Independent Code (PIC).

To resolve this issue, I kindly request that you recompile `libGpio.a`, `libLcdControl.a`, `libServoMotor.a`, and `libTimer.a` using the `-fPIC` option.

Your assistance would greatly advance my project. I truly appreciate your hard work and contributions!

Looking forward to your reply. Thank you!

robotdoly, 2024-11-08:
Hello @jonyhunter
Thank you for your interest in the Doly project. The current files are outdated. I’m working on an SDK, but right now, our focus is on Doly’s production. I’ll look into your request as soon as I have some free time. Thank you for your understanding and support.

jonyhunter, 2024-11-09:
@robotdoly Thank you very much for your response. I fully understand your current work priorities, and I look forward to your support in resolving the issue soon, as I have been eagerly anticipating Doly for a long time!

jonyhunter, 2024-11-09:
@robotdoly Additionally, may I ask which programming languages are included in the SDK you mentioned that is currently in development? Does it include an SDK for Java or Python?

robotdoly, 2024-11-09:
@jonyhunter Thanks for your understanding and support. Working on C++ and Python.

jonyhunter, 2024-11-11:
@robotdoly It’s wonderful to hear that you’re developing an SDK for Python! This will greatly reduce the cost of customizing Doly. Could you let me know approximately how long it will be before the SDK is released? I truly can’t wait!

robotdoly, 2024-11-12:
@jonyhunter , it’s difficult to give a promised release date for the SDK. I have limited resources and manpower, so our current focus is on completing the manufacturing process. Once that’s done, we’ll shift our attention to the software side. Thank you for your understanding and support.

jonyhunter, 2024-11-23:
@robotdoly Thank you for taking the time to respond so promptly despite your busy schedule. As a loyal fan of Doly, I’m eagerly looking forward to receiving it soon. However, as you know, waiting can be quite painful. Could I kindly ask you to compile a library file with the -fPIC parameter? This would allow us to continue developing some exciting features while we wait, making the waiting period feel much shorter.

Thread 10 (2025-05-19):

Eagerly Anticipating the Python SDK for Doly Robot

2061360308, 2025-05-19:
I’m excited to share that I’ve recently invested 1000 RMB in materials to replicate the Doly robot. To keep costs down, I sourced many components second-hand, including a Raspberry Pi CM4. Currently, I’ve completed the material collection phase, but I haven’t started the assembly process yet. I’m looking forward to diving into the build soon!

**High Hopes for the Python SDK**

I know you previously mentioned plans to develop a Python driver SDK for the Doly robot, but understand that you’re occupied with other priorities at the moment. Even so, I wanted to express my enthusiasm and anticipation for the future release of this SDK. Python is my preferred language due to its simplicity and extensive community support, and having an official SDK would make it much easier for me to control and customize the Doly robot during my replication project. It’ll open up endless possibilities for development!

**Offer of Support**

Once the Python SDK enters the development or testing phase, I’d be happy to help out. Whether it’s testing on my replicated Doly setup or providing feedback, I’m eager to contribute to making the SDK as robust as possible.

Thank you for your continued work on this amazing project! I can’t wait to see the Python SDK come to fruition and bring my Doly replication to life.

Grandpa-Gray1, 2025-05-20:
Great!

robotdoly, 2025-05-21:
Thanks so much for your support and enthusiasm! We're currently focused on completing the production process, it’s our number one priority right now. It’s been more demanding than expected and has caused some delays, but we’re almost through. Once production wraps up, we plan to release the C++ SDK/API first, followed by the Python wrapper. We really appreciate your patience and your offer to help, looking forward to sharing more soon!

Grandpa-Gray1, 2025-05-22:
Can you supply a parts & vendor list along with PBC source?Sent from my iPhoneOn May 21, 2025, at 12:03 PM, Levent Erenler ***@***.***> wrote:
robotdoly left a comment (robotdoly/DOLY-DIY#10)
Thanks so much for your support and enthusiasm! We're currently focused on completing the production process, it’s our number one priority right now. It’s been more demanding than expected and has caused some delays, but we’re almost through. Once production wraps up, we plan to release the C++ SDK/API first, followed by the Python wrapper. We really appreciate your patience and your offer to help, looking forward to sharing more soon!

—Reply to this email directly, view it on GitHub, or unsubscribe.You are receiving this because you commented.Message ID: ***@***.***>

2061360308, 2025-06-08:
> 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
>
>**This is my latest achievement.**

# Missing Charge Connector Drawing and Request for More Detailed Instructions

## Issue Description

While following the charging dock assembly instructions, I encountered the following issues:

1. The instructions state:
   ```
   Charge Connectors
   * Print attached connector drawing with 1:1 scale
   * Paste printed paper to Phosphor Bronze sheet with double sided tape
   * Cut from outer edges
   * Bend edges as shown
   * Remove tape and paper
   ```
   However, I cannot find this connector drawing in the repository. Where can I find this file?

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

2. The instructions regarding the following components are too brief:
   - The self-made copper plate parts in the charging dock
   - The copper plate touch sensor in the head section

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

## Requested Improvements

I would appreciate if you could provide:
1. The location or file of the connector drawing
2. More detailed instructions on making the copper plate components
3. If possible, clearer photos of the actual components for reference

Thank you for your help!

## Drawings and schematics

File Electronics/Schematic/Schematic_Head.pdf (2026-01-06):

+3.3V

## GND

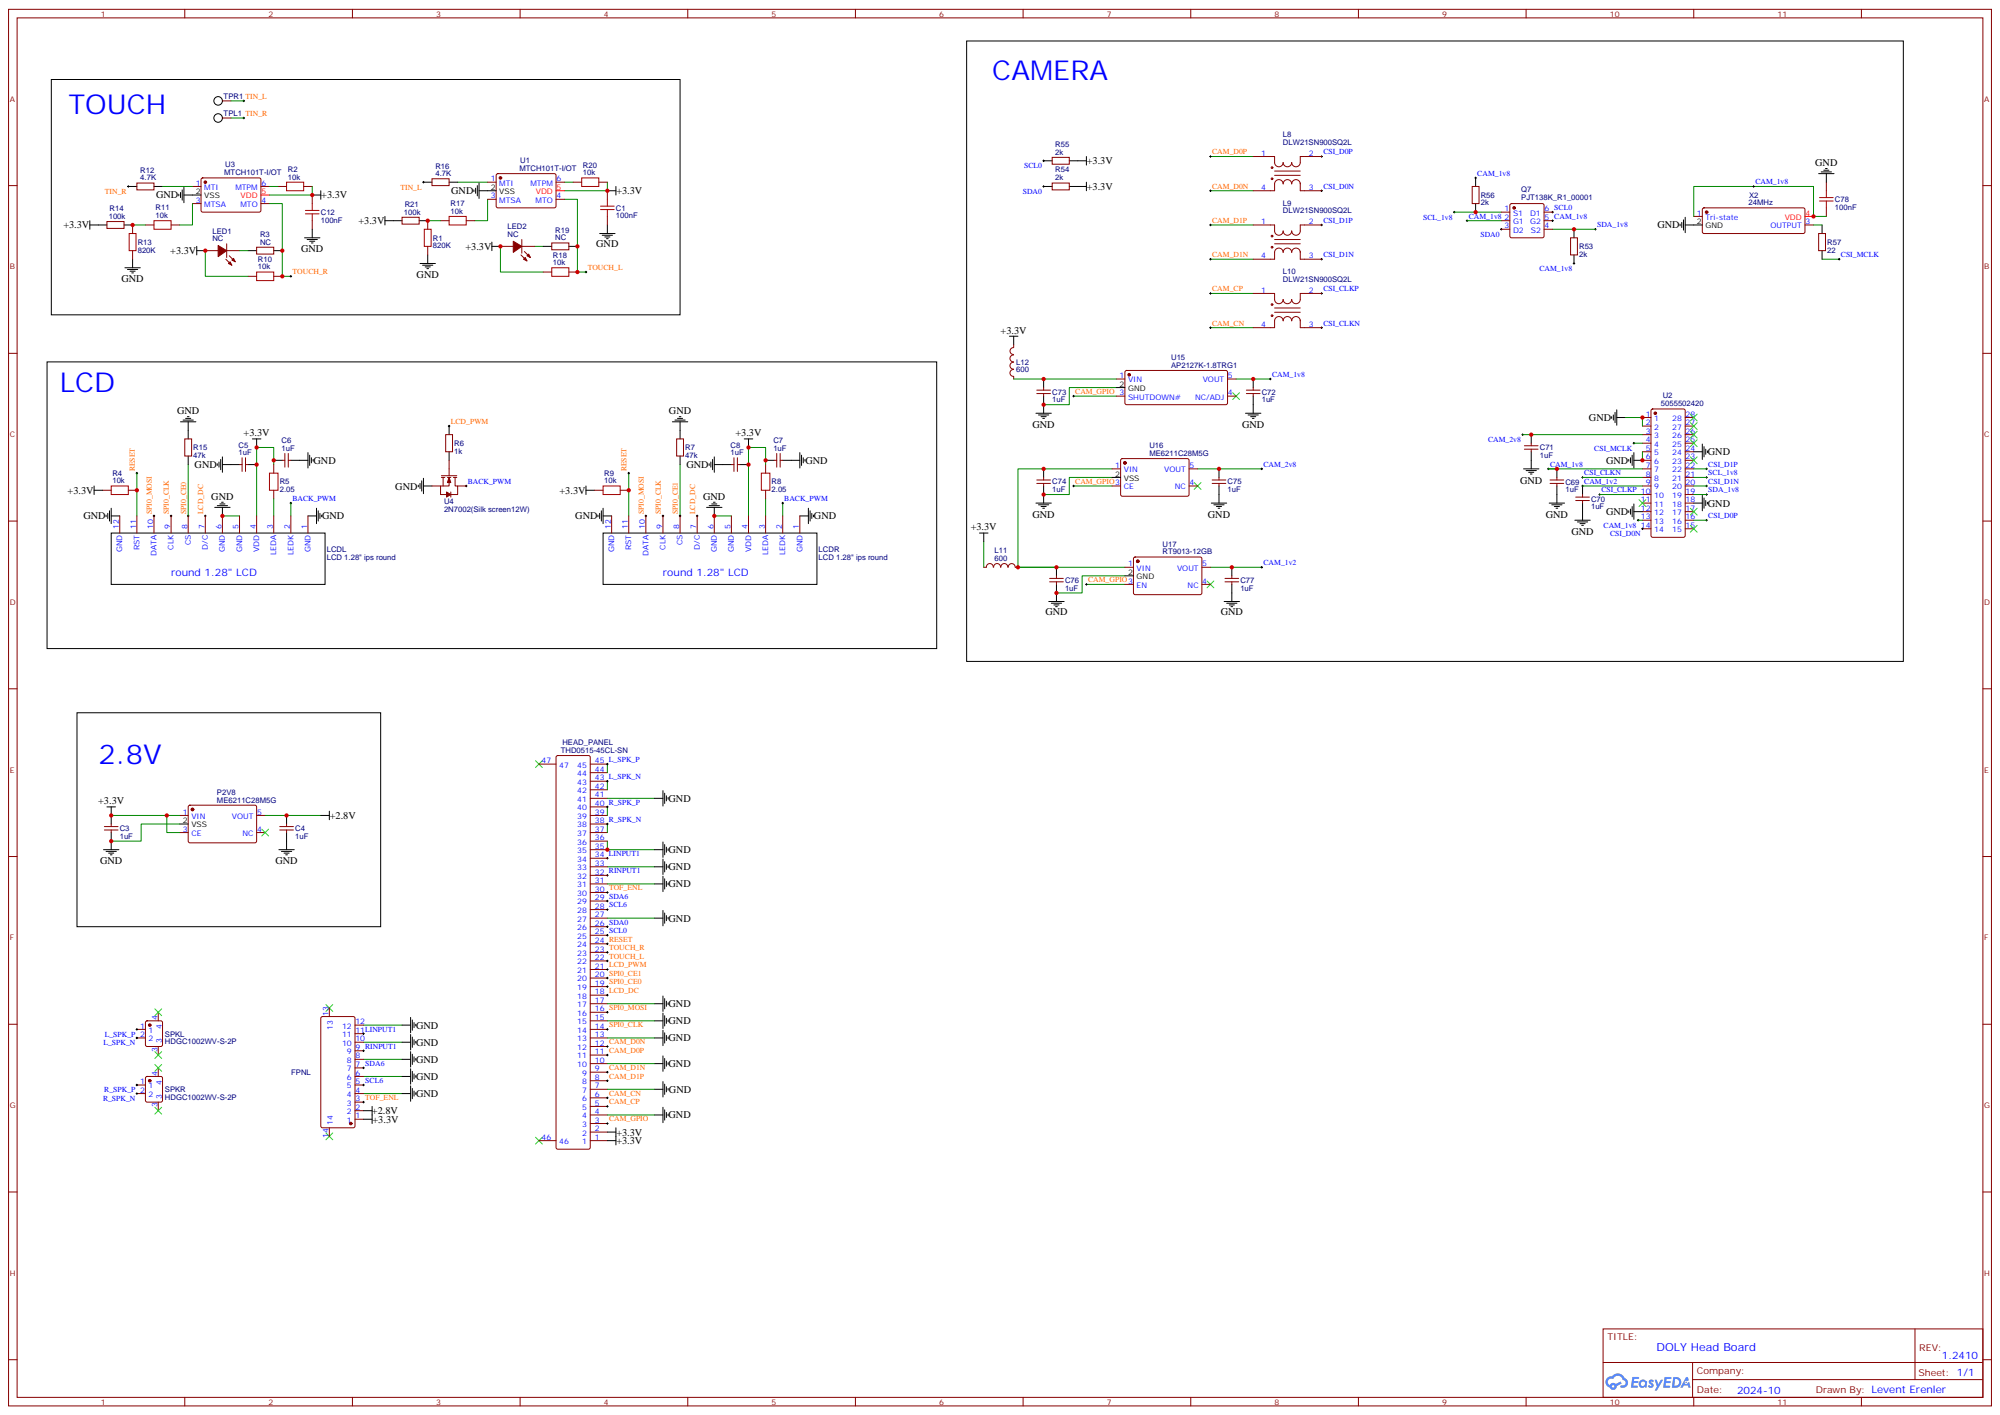
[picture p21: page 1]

Drawn By: Levent Erenler

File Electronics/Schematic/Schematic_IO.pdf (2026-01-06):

## GND

+5V

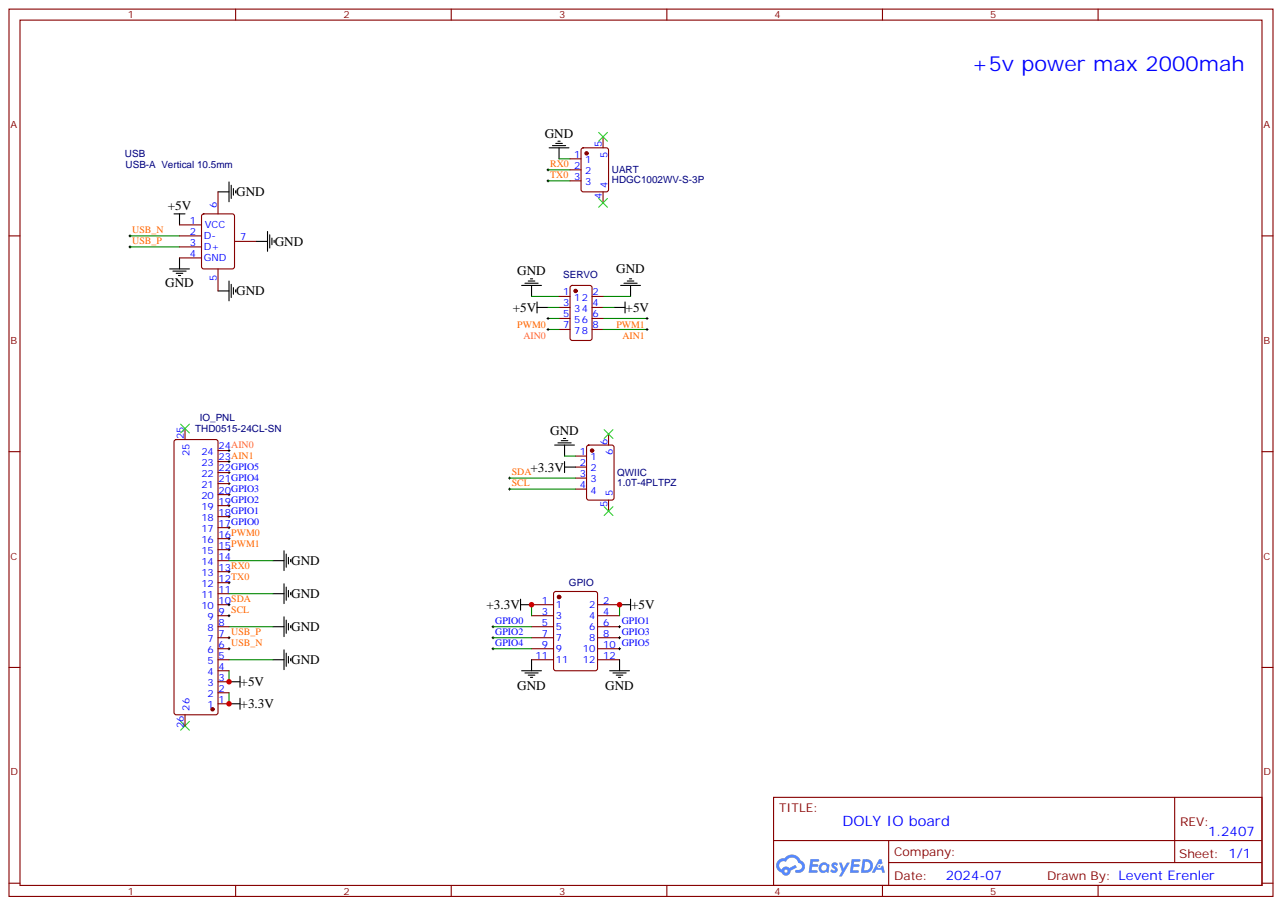
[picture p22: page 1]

Drawn By: Levent Erenler

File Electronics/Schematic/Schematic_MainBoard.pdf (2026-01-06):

A | A
B | B

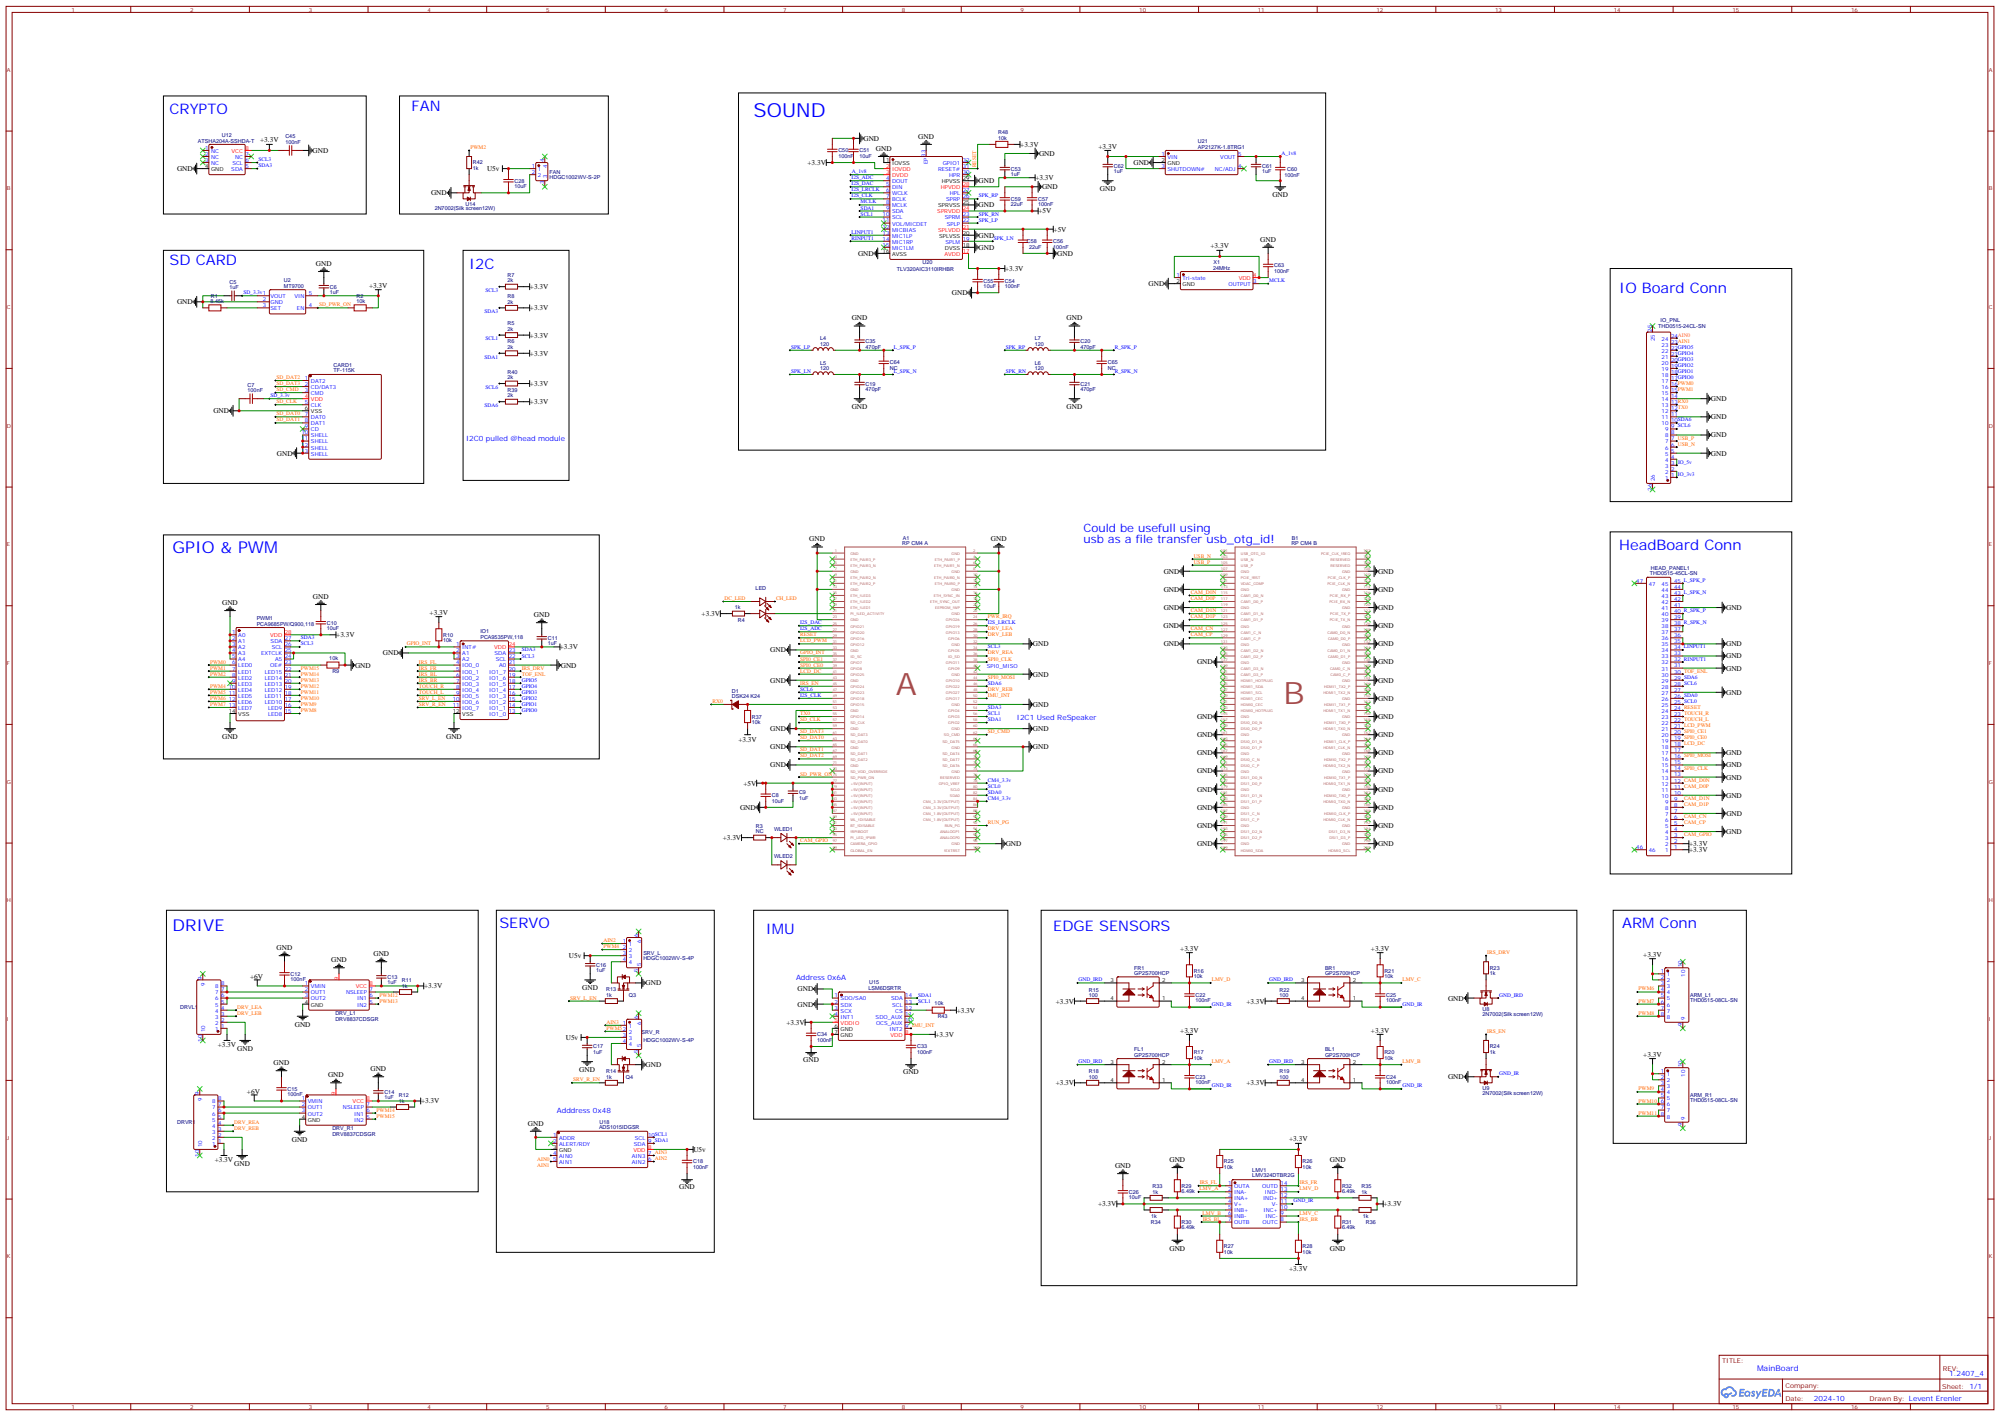
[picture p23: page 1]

Could be usefull using
usb as a file transfer usb_otg_id!

Drawn By: Levent Erenler

A | A

1

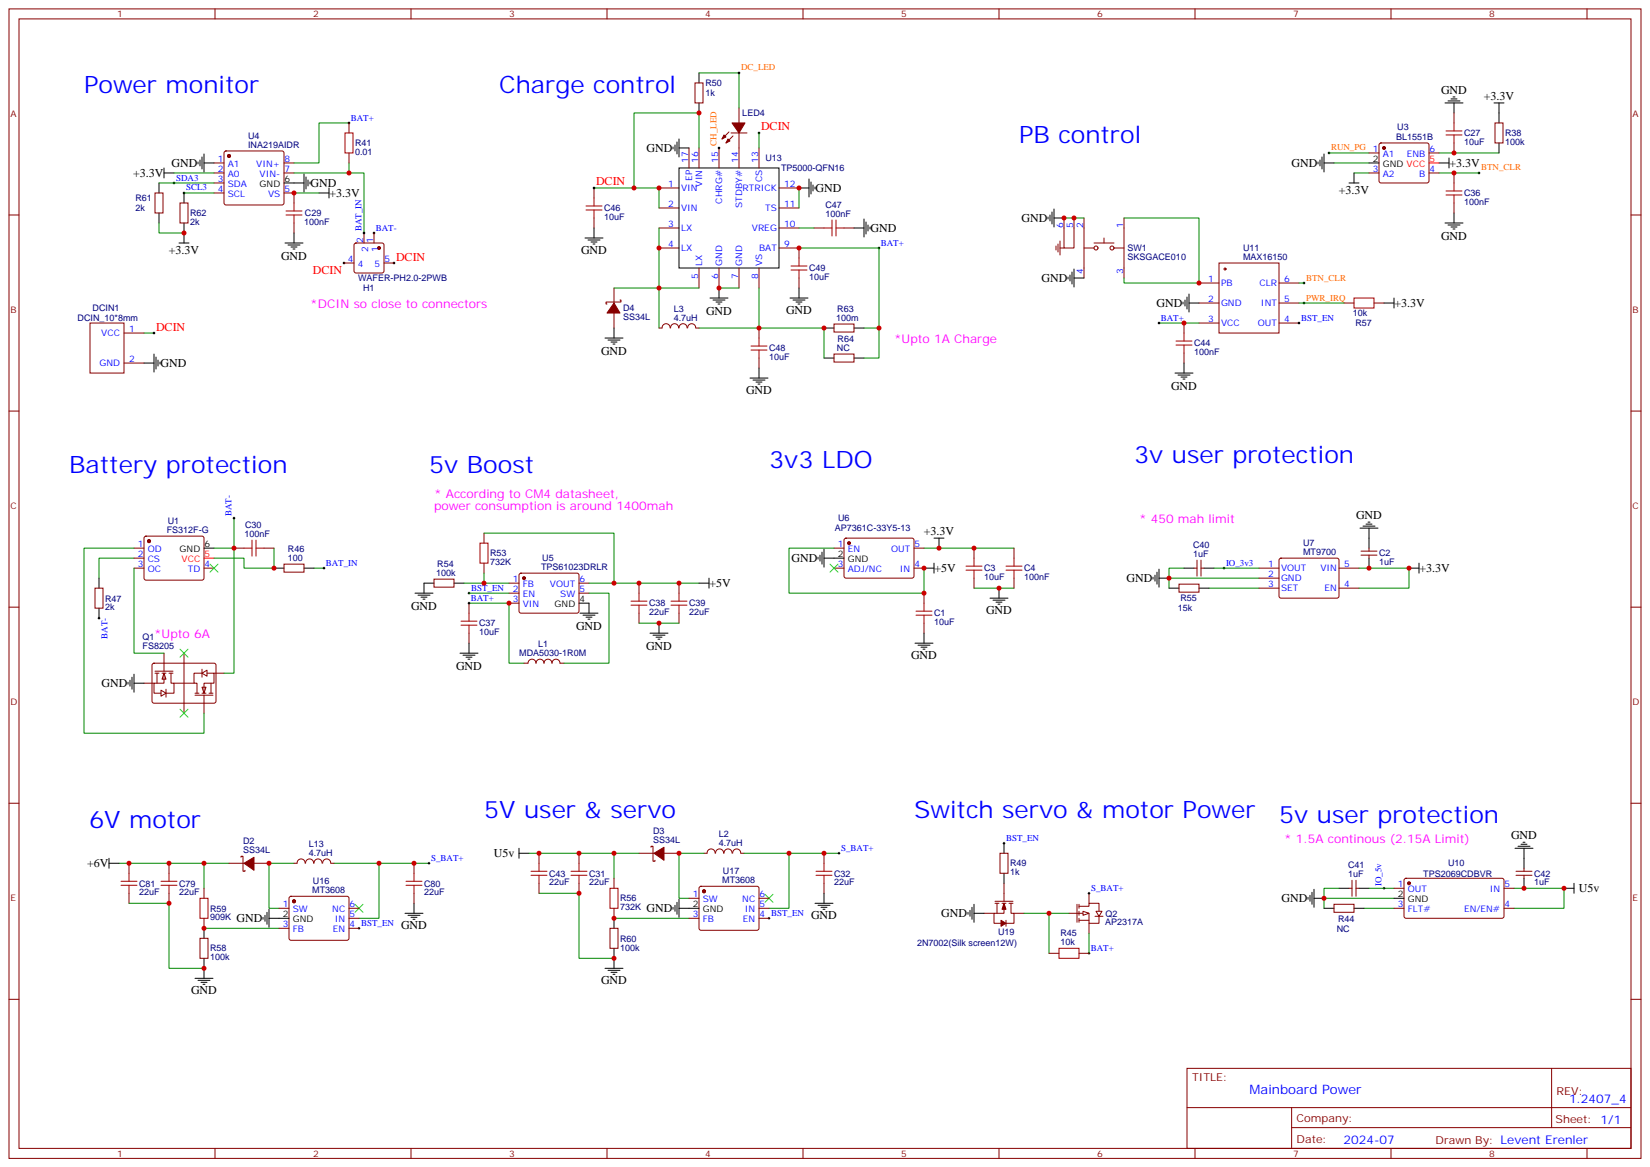
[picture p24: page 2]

*DCIN so close to connectors

* According to CM4 datasheet,
power consumption is around 1400mah

Switch servo & motor Power

Drawn By: Levent Erenler

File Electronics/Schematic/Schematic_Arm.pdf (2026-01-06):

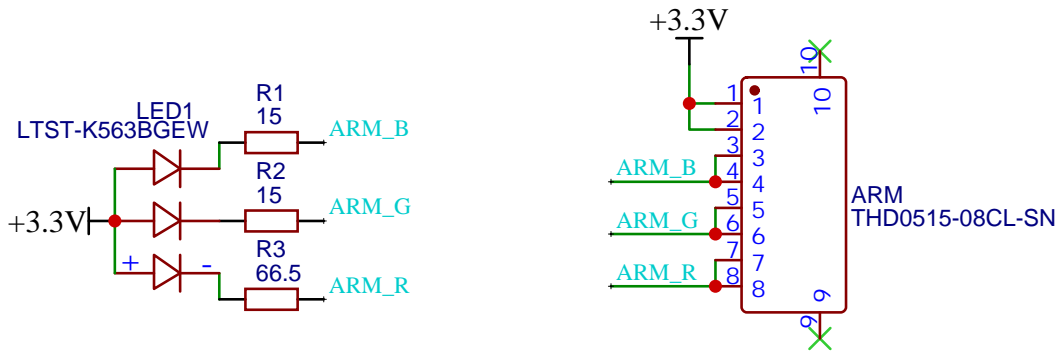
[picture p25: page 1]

Drawn By: Levent Erenler

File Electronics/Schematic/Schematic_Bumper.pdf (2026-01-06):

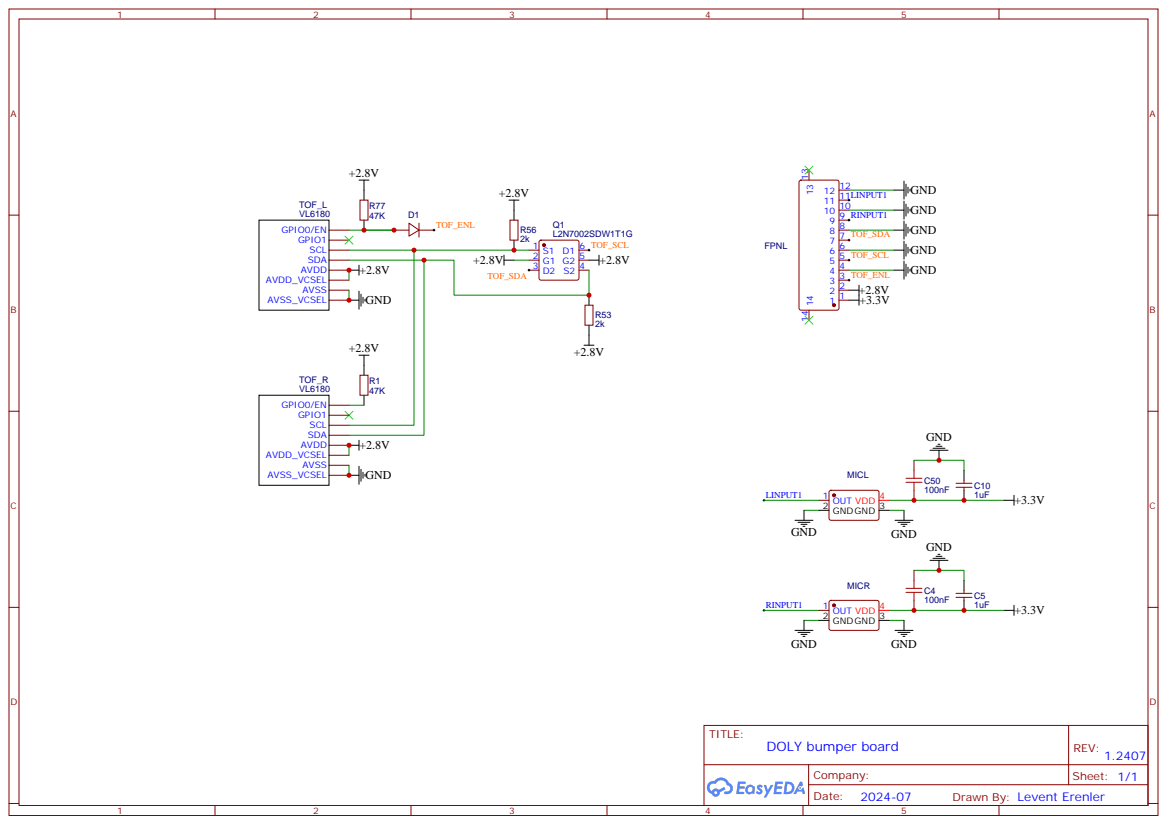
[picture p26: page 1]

Drawn By: Levent Erenler

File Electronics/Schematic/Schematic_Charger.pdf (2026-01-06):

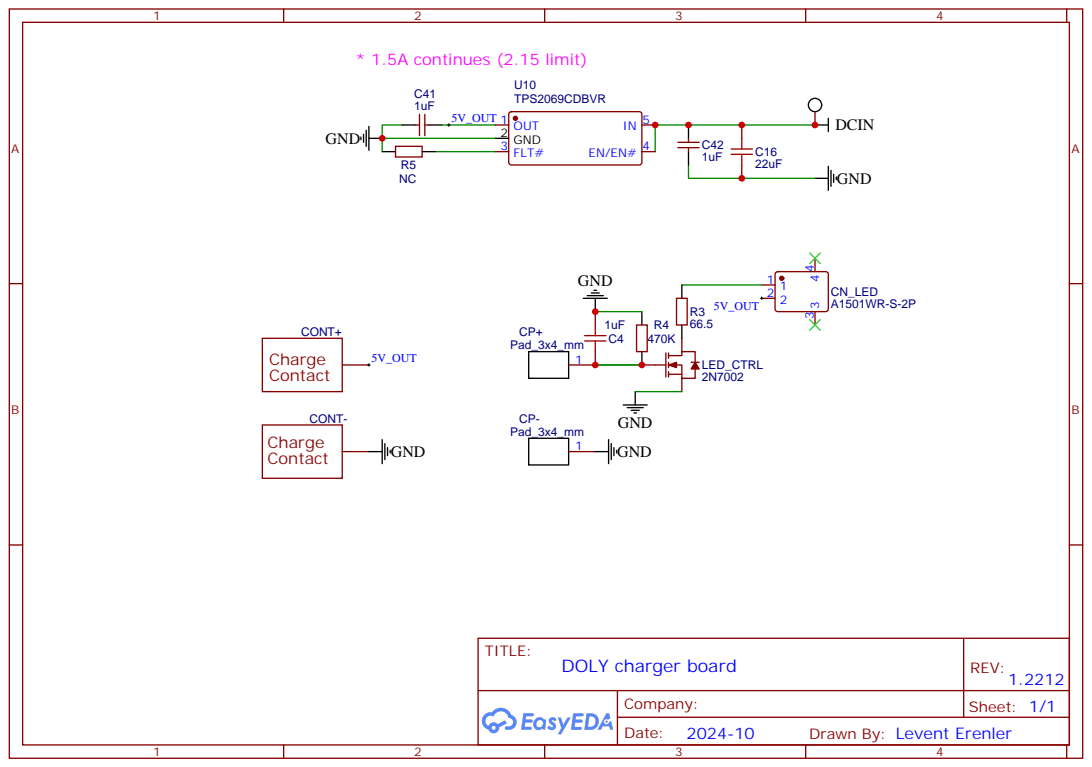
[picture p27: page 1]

Drawn By: Levent Erenler

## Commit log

2023-04-05 Add files via upload
    missing encoder files
2024-06-13 missing charger files
2025-05-27 Missing IO Board Source
2025-05-30 missing IO board json file
2025-10-21 swtich to v1.0
    [FDM_IO_lid.STL, FDM_LCD_aligner.STL, FDM_aligner.STL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]
2025-10-21 switch to v1.0
    [BOM_Arm.csv, BOM_Bumper.csv, BOM_Charger.csv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]
2025-10-21 Switching to v1.0
2026-03-25 add-on update
    [crane_arm.STEP, crane_arm.STL, crane_arm_cover.STEP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]
2026-10-15 Motor Compatibility
